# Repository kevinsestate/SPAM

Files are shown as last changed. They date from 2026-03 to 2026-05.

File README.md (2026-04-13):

# SPAM — Scanner for Polarized Anisotropic Materials

A local desktop application for scanning and extracting electromagnetic material tensors (ε, μ) from polarized RF measurements. Runs standalone on Raspberry Pi — no web server required.

## Features

- **Dual-polarization sweep**: Two full 0°–80° arm sweeps per run — horn at 0° (horizontal) then 90° (vertical) — servo-controlled automatically
- **Real-time S-parameter display**: Live S₂₁/S₁₁ magnitude and phase at each angle
- **T-matrix extraction**: Progressive inverse solver extracts diagonal ε/μ tensors from the full dual-pol S-matrix
- **Calibrated measurements**: Through + Reflect calibration sweep stores per-angle reference voltages
- **Live ADC oscilloscope**: Background I/Q stream at ~300 samp/s displayed in GUI
- **Data export**: JSON and CSV with all S-param fields + extraction results appended
- **Debug log**: All events written to `~/SPAM/spam_run.log` (survives crashes)
- **Remote access**: VNC-capable (x11vnc on X11 session) for headless operation

## Current Implementation Status (2026-04-13)

- **AD7193 SPI**: Operational — `ID=0xA2`, finite I/Q at 4800 Hz data rate, 4 MHz SPI
- **Motor control**: I2C polling of MCU status register (GPIO ISR not available on this kernel)
- **Servo**: HPS-2518MG on GPIO 18 — calibrated 850 µs = 0° (H), 1800 µs = 90° (V); jitter-free (PWM released after each move)
- **Dual-pol sweep**: Sweep 1 at horn 0°, servo rotates to 90°, Sweep 2 at horn 90°, returns home
- **RF switch**: Code complete — enable in Settings → Connection Setup once switch is physically wired
- **Calibration**: Through + Reflect sweep at pol-0 implemented; pol-90 cal deferred
- **Extraction**: Fires automatically after dual sweep if calibration data is loaded; builds 4×4 S-matrix from paired pol-0/pol-90 measurements

## Tech Stack

- **Python 3.9+**: Core application language
- **Tkinter**: GUI framework (included with Python)
- **Matplotlib**: Data visualization and graphing
- **SQLAlchemy**: ORM for database operations
- **SQLite**: Local database (no server required)

## Project Structure

```
SPAM/
├── GUI.py                  # Thin entry point (backward compat)
├── app.py                  # Application assembly (SPAMGui from mixins)
├── __main__.py             # Enables: python -m spam
├── pyproject.toml          # Python packaging config
├── requirements.txt        # Legacy dependency list
├── start_spam.sh           # Startup script for Linux/Raspberry Pi
├── start_spam.bat          # Startup script for Windows
├── spam_config.json        # GUI / ADC connection defaults (local)
├── spam_calc.py            # Backward-compat shim -> core/
├── spam_optimizer.py       # Backward-compat shim -> core/
├── core/
│   ├── spam_calc.py        # Transmission-matrix math (forward + S->T)
│   └── spam_optimizer.py   # Progressive inverse extraction
├── docs/                   # Handoff, benchmarks, integration notes, hardware PDFs (see docs/README.md)
├── gui/
│   ├── themes.py           # Theme palettes and fonts
│   ├── widgets.py          # Styled widget factory
│   ├── config.py           # Config persistence
│   ├── hardware_mixin.py   # Hardware init and motor control
│   ├── db_helpers.py       # Database CRUD helpers
│   ├── measurement.py      # Measurement sweep worker
│   ├── extraction.py       # Material extraction worker
│   ├── graphs.py           # Center panel graphs
│   ├── callbacks.py        # Status, calibrate, export, help
│   ├── debug_console.py    # Debug console window
│   ├── panels/             # Menu, status bar, sidebar, detail panel
│   └── dialogs/            # Extraction, parameters, connection dialogs
├── backend/
│   ├── database.py         # Database configuration
│   └── models.py           # SQLAlchemy models
├── hardware/
│   ├── ad7193.py           # AD7193 ADC driver (SPI)
│   ├── rf_switch.py        # RF switch controller (GPIO)
│   └── servo.py            # HPS-2518MG servo driver (pigpio/RPi.GPIO)
├── tests/
│   ├── test_spam_calc.py   # T-matrix validation tests
│   └── test_optimizer.py   # Extraction validation tests
├── scripts/pi/             # Raspberry Pi utilities (ADC, servo calibration)
├── Simulated Spam Calculations/
│   ├── *.mat               # Simulated validation datasets
│   └── *.m                 # MATLAB reference scripts
├── archive/
│   └── legacy/             # Non-active archived artifacts (includes old GUI snapshots)
└── README.md
```

Local runtime files (often gitignored): `spam.db`, `venv/`, `__pycache__/`, `spam_scanner.egg-info/`.

### Raspberry Pi ADC scripts (`scripts/pi/`)

Build and run on the Pi (Linux only; requires SPI enabled and `g++` for C++ tools):

| Script / binary | Purpose |
|---|---|
| `check_adc_lowlevel.py` | Short I/Q sanity check; optional `--benchmark-raw`, `--binary-out`, `--result-json` |
| `live_adc_view.py` | Live plot and/or benchmark; use `--data-rate`, `--spi-speed`, `--mode max-rate`, `--acq-mode stream`, `--benchmark-raw`, `--result-json` |
| `adc_fast_capture.py` | Optional native fast path hook + Python fallback |
| `servo_test.py` | **Interactive servo calibration** — `scan`, `sweep`, `min<us>`, `max<us>`, angle commands |
| `spi_ad7193_benchmark.cpp` | Raw SPI throughput vs clock (not full ADC protocol) |
| `ad7193_cpp_benchmark.cpp` | Full AD7193 driver in C++ + **pair/s** benchmark (compare to `live_adc_view.py`) |

Example (high output rate, benchmark only):

```bash
cd SPAM && source venv/bin/activate
python scripts/pi/live_adc_view.py --data-rate 4800 --spi-speed 2000000 \
  --mode max-rate --acq-mode stream --benchmark-raw --no-plot --duration 30 --result-json
```

Compile C++ tools:

```bash
cd SPAM/scripts/pi
g++ -O3 -std=c++17 spi_ad7193_benchmark.cpp -o spi_ad7193_benchmark
g++ -O3 -std=c++17 ad7193_cpp_benchmark.cpp -o ad7193_cpp_benchmark
```

(`-O3` uses the letter **O**, not zero.)

### Active vs Archive

- **Active runtime/test path**: `app.py`, `GUI.py`, `core/`, `gui/`, `backend/`, `hardware/`, `tests/`, startup scripts.
- **Archive path**: `archive/legacy/` contains non-active or superseded artifacts kept for reference (not used by launch scripts).

## Installation

### Prerequisites

- **Python 3.9 or higher**
- **Tkinter** (GUI framework - usually included with Python)
  - On Raspberry Pi/Linux: `sudo apt-get install python3-tk`
  - On Windows/Mac: Usually pre-installed with Python

### Windows Installation

#### Option 1: Quick Start (Recommended)

1. **Download or clone the repository:**
   ```powershell
   git clone https://github.com/kevinsestate/SPAM.git
   cd SPAM
   ```

2. **Run the startup script:**
   ```powershell
   .\start_spam.bat
   ```
   
   The script will automatically:
   - Check if Python is installed
   - Create a virtual environment (if needed)
   - Install the project and all dependencies
   - Launch the GUI application

#### Option 2: pip install (Standard Python)

1. **Clone and install:**
   ```powershell
   git clone https://github.com/kevinsestate/SPAM.git
   cd SPAM
   pip install -e .
   ```

2. **Launch (any of these work):**
   ```powershell
   spam                # CLI entry point
   python -m spam      # Module entry point
   python GUI.py       # Direct script
   ```

#### Option 3: Manual Installation

1. **Navigate to the project directory:**
   ```powershell
   cd SPAM
   ```

2. **Create a virtual environment:**
   ```powershell
   python -m venv venv
   .\venv\Scripts\activate
   ```
   
   If you get an execution policy error:
   ```powershell
   Set-ExecutionPolicy -ExecutionPolicy RemoteSigned -Scope CurrentUser
   ```

3. **Install:**
   ```powershell
   pip install -e .
   ```

4. **Run:**
   ```powershell
   spam
   ```

### Linux / Raspberry Pi Installation

#### Option 1: Quick Start (Recommended)

1. **Clone or download the repository:**
   ```bash
   git clone https://github.com/kevinsestate/SPAM.git
   cd SPAM
   chmod +x start_spam.sh
   ```

2. **Run the application:**
   ```bash
   ./start_spam.sh
   ```
   
   The script will automatically:
   - Check if Python 3 is installed
   - Create a virtual environment (if needed)
   - Install the project and all dependencies
   - Launch the GUI application

#### Option 2: pip install (Standard Python)

1. **Clone and install:**
   ```bash
   git clone https://github.com/kevinsestate/SPAM.git
   cd SPAM
   pip install -e .
   ```

   For Raspberry Pi with hardware support:
   ```bash
   pip install -e ".[rpi]"
   ```

2. **Launch:**
   ```bash
   spam                # CLI entry point
   python -m spam      # Module entry point
   python3 GUI.py      # Direct script
   ```

#### Option 3: Manual Installation

1. **Install Tkinter (if not already installed):**
   ```bash
   sudo apt-get update
   sudo apt-get install python3-tk
   ```

2. **Set up and install:**
   ```bash
   cd SPAM
   python3 -m venv venv
   source venv/bin/activate
   pip install -e .
   ```

3. **Run:**
   ```bash
   spam
   ```

## Usage Guide

### First Time Setup

1. **Configure Connection Settings** (if using hardware):
   - Go to **Settings → Connection Setup**
   - Configure signal input settings (ADC channels, sampling rate, etc.)
   - Configure serial port settings (if using serial connection)
   - Click **"Save"** to store settings

2. **Adjust Measurement Parameters** (optional):
   - Go to **Settings → Adjust Parameters**
   - Set frequency, power level, angle step, and measurement interval
   - Click **"Save"** to apply changes

### Calibration Process

Before taking measurements, calibrate the system to convert raw ADC voltages to S-parameters:

1. Click **"Calibrate"** in the sidebar
2. **Step 1 — Through (empty fixture):**
   - Remove ALL material from the fixture
   - Click **OK** — arm sweeps 0°→80°, records per-angle transmitted voltage
3. **Step 2 — Reflect (metal sheet):**
   - Place a metal sheet in the fixture
   - Click **OK** — arm sweeps again, records reflected voltage
4. Calibration stored in DB — loaded automatically on next launch

> **Note:** Set `cal_d_m` and `cal_d_sheet_m` in **Settings → Connection Setup** to your physical rig geometry (metres) for accurate phase correction. Default is 0.0 (phase correction disabled).

### Taking Measurements

1. **Start a Measurement Session:**
   - Click **"Start Measurement"** in the sidebar
   - **Sweep 1**: arm sweeps 0°→80° at 5° steps with horn at 0° (horizontal)
   - Servo automatically rotates horn to 90°
   - **Sweep 2**: arm sweeps 0°→80° with horn at 90° (vertical)
   - Servo returns horn to 0° and extraction fires automatically
   - All data saved to DB in real-time

2. **Monitor Progress:**
   - Right panel shows: Angle, Polarization, Sweep progress (e.g. `Sweep 1/2 — 8/17 pts`), Cal Data status, live S₂₁/S₁₁
   - Center graphs: S-parameter plots with pol-0 (blue) and pol-90 (orange) colour coding, live ADC oscilloscope

3. **Stop Measurement:**
   - Click **"Stop Measurement"** — motors return home, servo resets to 0°

### Viewing Results

- **Real-Time Graphs:**
  - Center panel shows permittivity and permeability vs angle
  - Graphs update automatically every second
  - Scroll to view control parameters and non-idealities sections

- **Measurement Data Panel:**
  - Right panel displays latest measurement values
  - S-Parameters show magnitude and phase
  - System status indicates current state

- **View Results Summary:**
  - Click **"View Results"** to see statistics
  - Shows total measurements, angle range, min/max/average values

### Managing Data

1. **Clear Measurements:**
   - Click **"Clear Measurements"** to delete all data
   - Confirmation dialog will appear
   - **Warning:** This action cannot be undone

2. **Export Data:**
   - Click **"Export Data"** or use **File → Export Data**
   - Choose format:
     - **JSON**: measurements array + extraction result block (ε tensor, μ tensor, fit error)
     - **CSV**: one row per measurement point with all S-param fields; extraction result appended as footer
   - Data exported in chronological order (angle 0 = row 1)

### Understanding the Interface

**Left Sidebar:**
- Action buttons for calibration, measurement control, and data management
- Version information at the bottom

**Center Panel:**
- Real-time measurement graphs (Permittivity and Permeability)
- Control Parameters section (frequency, power, angle step, interval)
- Non-Idealities & Compensation section (calibration error, noise, temperature, humidity)

**Right Panel:**
- Measurement section: Angle, Polarization, Sweep progress, Cal Data status, Status
- Extracted Material: εr diagonal, μr diagonal, Fit Error
- Motor: status and position
- S-Parameters: live S₁₁, S₁₂, S₂₁, S₂₂
- Extraction Config: status, thickness, tensor type
- Parameters: frequency, power, angle step, interval

**Status Bar (Bottom):**
- Current system status
- Last update timestamp

### Database

- All measurements are stored in a local SQLite database (`spam.db`)
- The database is created automatically on first run
- No database server is required - everything runs locally
- Database file is stored in the project directory

## Hardware Integration

### System Architecture

**RF Chain (24 GHz):**
- **Gunn Diode Oscillator** → Amplifier → Splitter
  - TX path → TX Horn Antenna (radiates into free space through sample)
  - LO path → Mixer
- **RX Horn Antennas**: Transmitted (RXT) and Reflected (RXp)
- **SP2T RF Switch** (GPIO 22): selects TX or RX antenna path → Mixer input
- **Mixer**: downconverts to IF — produces IF-I and IF-Q
- **AD7193 (Pmod AD5)**: 24-bit SPI ADC reads IF-I and IF-Q at 4800 Hz

**Control System (Raspberry Pi):**
- **AD7193** via SPI (`/dev/spidev0.0`, 4 MHz)
- **Motor controller MCU** via I2C (address `0x55`) — 2-axis arm + material rotation
- **HPS-2518MG Servo** via GPIO 18 PWM (pigpio) — rotates horn antenna for polarization
- **SP2T RF Switch** via GPIO 22 (optional, enable in settings)

### Connection Setup

All hardware parameters are in **Settings → Connection Setup**:

| Setting | Default | Notes |
|---|---|---|
| SPI Bus / CS | 0 / 0 | AD7193 on SPI0.0 |
| SPI Speed | 4000000 | 4 MHz |
| ADC Gain | 1 | Increase for weak signals |
| Data Rate (Hz) | 4800 | Higher = faster, more noise |
| Samples/Point | 8 | Averaged per angle |
| Enable RF Switch | 0 | Set to 1 once switch is wired |
| Switch GPIO Pin | 22 | BCM numbering |
| Servo GPIO Pin | 18 | BCM numbering |
| MCU Address | 0x55 | I2C motor controller |
| ISR Pin | 17 | Motor position interrupt |
| Coupler Sep. d (m) | 0.0 | **Measure and set for calibration** |
| Ref Plane d_sheet (m) | 0.0 | **Measure and set for calibration** |

### Servo Calibration

To recalibrate the horn servo (e.g. after mechanical adjustment):

```bash
cd ~/SPAM
python3 scripts/pi/servo_test.py
```

Use `scan` to find physical stops, `min<us>` / `max<us>` to set endpoints, `sweep` to verify, `q` to print final values. Update `_PULSE_MIN_US` / `_PULSE_MAX_US` in `hardware/servo.py`.

### Remote Access (VNC)

Enable x11vnc on the Pi (X11 session required — run `sudo raspi-config nonint do_wayland W1` first if on Wayland):

```bash
x11vnc -display :0 -nopw -forever -bg -noxdamage
# Connects on port 5901
```

Connect from Windows using RealVNC Viewer: `<pi-ip>:5901`

## Troubleshooting

### Tkinter not found (Linux/Raspberry Pi)
```bash
sudo apt-get update
sudo apt-get install python3-tk
```

### Permission denied on startup script
```bash
chmod +x start_spam.sh
```

### Database errors
- The database file (`spam.db`) is created automatically
- If you encounter errors, try deleting `spam.db` and restarting the application

### Display issues on Raspberry Pi
- If the GUI doesn't appear, make sure you're running in a graphical environment
- For headless setups, you may need to set up X11 forwarding or use a VNC server

## Development

### Adding New Features

The application uses a mixin-based architecture:
- `app.py`: Assembles `SPAMGui` from mixin classes
- `gui/`: Mixin modules (widgets, config, hardware, measurement, extraction, graphs, etc.)
- `core/`: Scientific computation (T-matrix math, inverse solver)
- `backend/`: Database models and configuration
- `hardware/`: ADC and RF switch drivers
- `tests/`: Validation test suites

### Testing

**Automated math checks** (from repo root):

```bash
python tests/test_spam_calc.py
python tests/test_optimizer.py
```

**Manual / GUI:** calibration, measurement start/stop, export (JSON/CSV), live graphs.

## Notes

- This is a **local-only** application - no web server or network access required
- All data is stored locally in SQLite
- The application is designed to run standalone on a Raspberry Pi
- The web frontend (React) and FastAPI backend are no longer needed for local operation

## Integration testing and reports

- **Transmission-matrix / extraction (simulation):** [docs/integration/TRANSMISSION_MATRIX_INTEGRATION_TEST_RESULTS.md](docs/integration/TRANSMISSION_MATRIX_INTEGRATION_TEST_RESULTS.md)
- **ADC / RF switch software bring-up (hardware scope):** [docs/integration/INTEGRATION_TEST_RESULTS.md](docs/integration/INTEGRATION_TEST_RESULTS.md)
- **Benchmark summary + LaTeX report:** [docs/benchmarks/benchmark_results.md](docs/benchmarks/benchmark_results.md), [docs/benchmarks/benchmark_report.tex](docs/benchmarks/benchmark_report.tex)
- **Index of all docs:** [docs/README.md](docs/README.md)

## License

This project is provided as-is for educational and development purposes.

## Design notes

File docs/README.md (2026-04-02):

# Documentation index

| Path | Contents |
|---|---|
| [HANDOFF_STATUS.md](HANDOFF_STATUS.md) | Quick Pi / ADC / extraction handoff for operators and agents |
| [reference/hardware/](reference/hardware/) | AD7193 / Pmod AD5 PDFs and Raspberry Pi pinout image |
| [benchmarks/](benchmarks/) | `benchmark_results.md`, `benchmark_report.tex` (Overleaf), `artifacts/` (captured run logs) |
| [integration/](integration/) | Transmission-matrix and hardware integration test write-ups |

Run math validation from repo root:

```bash
python tests/test_spam_calc.py
python tests/test_optimizer.py
```

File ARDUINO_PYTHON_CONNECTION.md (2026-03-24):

# Arduino and Python Connection Guide

## Overview

There are several ways to connect Arduino with Python for the SPAM project. This guide explains the different methods, their pros/cons, and how they relate to your current setup.

## Connection Methods

### 1. Serial Communication (USB/UART)

**How it works:**
- Arduino connects to computer via USB cable
- Python uses `pyserial` library to communicate over serial port
- Data sent as text strings or binary data
- Works on Windows, Linux, and Mac

**Pros:**
- ✅ Simple and straightforward
- ✅ Works on all platforms
- ✅ No additional hardware needed (just USB cable)
- ✅ Easy to debug (can use Serial Monitor)
- ✅ Fast communication (up to 115200+ baud)

**Cons:**
- ❌ Requires USB cable connection
- ❌ One Arduino per USB port
- ❌ Not ideal for multiple devices

**Python Code Example:**
```python
import serial
import time

# Open serial connection
arduino = serial.Serial('COM3', 115200, timeout=1)  # Windows: COM3, Linux: /dev/ttyUSB0 or /dev/ttyACM0
time.sleep(2)  # Wait for Arduino to initialize

# Send command to move motor
arduino.write(b'M,1,45.0\n')  # Move motor 1 to 45 degrees

# Read response
response = arduino.readline().decode('utf-8').strip()
print(f"Arduino response: {response}")

# Close connection
arduino.close()
```

**Arduino Code Example:**
```cpp
void setup() {
  Serial.begin(115200);
}

void loop() {
  if (Serial.available() > 0) {
    String command = Serial.readStringUntil('\n');
    // Process command (e.g., "M,1,45.0" = Move motor 1 to 45°)
    processCommand(command);
  }
}
```

---

### 2. I2C Communication (Current Method)

**How it works:**
- Arduino acts as I2C slave device
- Raspberry Pi (or other I2C master) communicates via I2C bus
- Multiple devices can share same I2C bus (different addresses)
- Uses SDA (data) and SCL (clock) wires

**Pros:**
- ✅ Multiple devices on same bus (up to 128 addresses)
- ✅ Only 2 wires needed (plus power/ground)
- ✅ Standard protocol, well-supported
- ✅ Already implemented in your GUI code
- ✅ Good for Raspberry Pi integration

**Cons:**
- ❌ Requires I2C-capable hardware (Raspberry Pi, not standard PC)
- ❌ Limited distance (short wires)
- ❌ More complex than serial
- ❌ Address conflicts if not careful

**Your Current Implementation:**
Your GUI already uses I2C! In `GUI.py`, the `_initialize_motor_control()` function:
- Opens I2C bus using `SMBus`
- Communicates with microcontroller at address `0x55`
- Sends 6-byte commands: `[command, motor_num, float_bytes...]`

**Python Code (Already in your code):**
```python
from smbus import SMBus
import struct

bus = SMBus(1)  # I2C bus 1 on Raspberry Pi
address = 0x55  # Arduino I2C address

# Send motor position command
position = 45.0  # degrees
packed = struct.pack('<f', position)  # Pack as 4-byte float
message = [1, 1] + list(packed)  # [command, motor_num, float_bytes]
bus.write_i2c_block_data(address, 0x00, message)
```

**Arduino I2C Code:**
```cpp
#include <Wire.h>

#define I2C_ADDRESS 0x55

void setup() {
  Wire.begin(I2C_ADDRESS);
  Wire.onReceive(receiveEvent);
  Wire.onRequest(requestEvent);
}

void receiveEvent(int bytes) {
  byte data[6];
  int i = 0;
  while (Wire.available() && i < 6) {
    data[i++] = Wire.read();
  }
  // Process command: data[0]=command, data[1]=motor, data[2-5]=position
  processMotorCommand(data);
}

void requestEvent() {
  // Send status back to master
  Wire.write(statusByte);
}
```

---

### 3. Firmata Protocol

**How it works:**
- Arduino runs Firmata firmware (standard library)
- Python uses `pyfirmata` library
- High-level abstraction - control pins directly from Python
- No need to write Arduino code

**Pros:**
- ✅ Very easy to use
- ✅ No Arduino programming needed
- ✅ Direct pin control from Python
- ✅ Good for prototyping

**Cons:**
- ❌ Less efficient than custom code
- ❌ Limited to Firmata capabilities
- ❌ Not ideal for complex motor control
- ❌ Requires Firmata library on Arduino

**Python Code:**
```python
from pyfirmata import Arduino, util
import time

board = Arduino('COM3')  # or '/dev/ttyUSB0' on Linux

# Control digital pin
board.digital[9].write(1)  # Set pin 9 HIGH

# Read analog pin
value = board.analog[0].read()  # Read analog pin A0

board.exit()
```

---

## Comparison for Your SPAM Project

### Current Setup (I2C)
- **Status**: ✅ Already implemented
- **Hardware**: Raspberry Pi with I2C bus
- **Arduino**: Configured as I2C slave at address 0x55
- **Communication**: 6-byte commands for motor control
- **Best for**: Production system on Raspberry Pi

### Alternative: Serial Communication
- **Status**: ⚠️ Would need to modify GUI code
- **Hardware**: Any computer with USB port
- **Arduino**: Standard USB connection
- **Communication**: Text-based commands (e.g., "M,1,45.0")
- **Best for**: Development, Windows testing, simpler setup

---

## Integration with Your GUI

### Option 1: Keep I2C (Recommended for Raspberry Pi)
Your current setup is already working! The GUI:
1. Initializes I2C bus in `_initialize_motor_control()`
2. Sends commands via `_send_motor_command()`
3. Reads status via GPIO interrupts
4. Works seamlessly on Raspberry Pi

**No changes needed** if you're using Raspberry Pi!

### Option 2: Add Serial Support (For Windows/Development)
To add serial support alongside I2C:

1. **Add serial import:**
```python
import serial
```

2. **Modify `_initialize_motor_control()` to detect connection type:**
```python
def _initialize_motor_control(self):
    # Try I2C first (Raspberry Pi)
    if platform.system() == 'Linux':
        try:
            from smbus import SMBus
            # ... existing I2C code ...
        except:
            pass
    
    # Fall back to Serial (Windows or if I2C fails)
    try:
        port = self.connection_settings.get('serial_port', 'COM3')
        baud = int(self.connection_settings.get('serial_baud', '115200'))
        self.arduino_serial = serial.Serial(port, baud, timeout=1)
        self.motor_control_enabled = True
        self.motor_control_type = 'serial'
    except:
        self.motor_control_enabled = False
```

3. **Modify `_send_motor_command()` to support both:**
```python
def _send_motor_command(self, motor_num, position, command=1):
    if self.motor_control_type == 'i2c':
        # Existing I2C code
        ...
    elif self.motor_control_type == 'serial':
        # Serial command
        cmd = f"M,{motor_num},{position:.2f}\n"
        self.arduino_serial.write(cmd.encode())
        response = self.arduino_serial.readline().decode().strip()
        return response.startswith("OK")
```

---

## Recommended Approach

### For Raspberry Pi (Production):
**Use I2C** - Already implemented, efficient, supports multiple devices

### For Windows Development/Testing:
**Add Serial support** - Easier to test without Raspberry Pi hardware

### For Both:
**Hybrid approach** - Detect platform and use appropriate method:
- Linux → I2C
- Windows → Serial
- Fallback to simulation if neither works

---

## Arduino Code Requirements

### For I2C (Current):
- Arduino must be configured as I2C slave
- Address: 0x55 (or configurable)
- Must handle 6-byte commands: `[command, motor, float_bytes...]`
- Must send status via GPIO interrupt pin

### For Serial (Alternative):
- Arduino must read serial commands
- Parse text commands like "M,1,45.0"
- Send responses like "OK:POSITION:45.0"
- Handle status updates

---

## Troubleshooting

### I2C Issues:
- **"No device at address"**: Check I2C address, run `i2cdetect -y 1` on Pi
- **"Permission denied"**: Add user to `i2c` group: `sudo usermod -aG i2c $USER`
- **"Input/output error"**: Check wiring (SDA/SCL), verify power

### Serial Issues:
- **"Port not found"**: Check COM port (Windows Device Manager) or `/dev/tty*` (Linux)
- **"Permission denied"**: Add user to `dialout` group: `sudo usermod -aG dialout $USER`
- **"Timeout"**: Check baud rate matches Arduino code

---

## Summary

**Your current I2C setup is perfect for Raspberry Pi!** It's already integrated and working. If you need to test on Windows or want a simpler development setup, you can add serial communication as an alternative. The choice depends on:

- **Platform**: Raspberry Pi → I2C, Windows → Serial
- **Complexity**: I2C is more complex but more capable
- **Multiple devices**: I2C supports multiple devices on one bus
- **Distance**: Serial works over longer USB cables

Both methods work well - I2C is better for production, Serial is easier for development!

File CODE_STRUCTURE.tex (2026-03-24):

\documentclass[11pt,a4paper]{article}
\usepackage[utf8]{inputenc}
\usepackage[T1]{fontenc}
\usepackage{geometry}
\usepackage{graphicx}
\usepackage{hyperref}
\usepackage{listings}
\usepackage{xcolor}
\usepackage{amsmath}
\usepackage{tikz}
\usepackage{float}
\usepackage{enumitem}

% Page setup
\geometry{margin=1in}
\hypersetup{
    colorlinks=true,
    linkcolor=blue,
    filecolor=magenta,      
    urlcolor=cyan,
    pdftitle={SPAM Code Structure},
    pdfauthor={SPAM Development Team}
}

% Code listing style
\lstset{
    language=Python,
    basicstyle=\ttfamily\small,
    keywordstyle=\color{blue}\bfseries,
    commentstyle=\color{green!60!black},
    stringstyle=\color{red},
    numbers=left,
    numberstyle=\tiny\color{gray},
    stepnumber=1,
    numbersep=5pt,
    backgroundcolor=\color{gray!10},
    frame=single,
    breaklines=true,
    breakatwhitespace=true,
    tabsize=4,
    showspaces=false,
    showstringspaces=false
}

\title{\textbf{SPAM Code Structure Documentation}\\
\large Scanner for Polarized Anisotropic Materials\\
\large Code Architecture Overview}
\author{SPAM Development Team}
\date{\today}

\begin{document}

\maketitle
\tableofcontents
\newpage

\section{Project Overview}

The SPAM (Scanner for Polarized Anisotropic Materials) project is a Python-based desktop application for automated material characterization. The codebase is organized into a modular structure with clear separation between GUI, database, and hardware control components.

\section{Project Structure}

\subsection{Directory Layout}
\begin{verbatim}
SPAM/
├── GUI.py                    # Main application file
├── motor_control_status.py   # Motor control reference
├── requirements.txt          # Python dependencies
├── start_spam.sh            # Linux startup script
├── start_spam.bat           # Windows startup script
├── spam_config.json         # Configuration file (auto-generated)
├── spam.db                  # SQLite database (auto-generated)
├── backend/
│   ├── __init__.py          # Package marker
│   ├── database.py          # Database configuration
│   └── models.py            # Database models
└── venv/                    # Virtual environment
\end{verbatim}

\subsection{Key Files}

\begin{description}
    \item[\texttt{GUI.py}] Main application file containing the entire GUI and application logic (3000+ lines)
    \item[\texttt{backend/database.py}] Database connection and session management
    \item[\texttt{backend/models.py}] SQLAlchemy ORM models for data storage
    \item[\texttt{motor\_control\_status.py}] Reference implementation for motor control
    \item[\texttt{requirements.txt}] Python package dependencies
    \item[\texttt{start\_spam.sh/bat}] Platform-specific startup scripts
\end{description}

\section{Main Components}

\subsection{GUI.py - Main Application}

\texttt{GUI.py} is the core of the application, containing a single main class that handles all functionality.

\subsubsection{SPAMGui Class}
The \texttt{SPAMGui} class inherits from \texttt{tk.Tk}, making it the main application window.

\textbf{Key Responsibilities:}
\begin{itemize}
    \item GUI component creation and layout
    \item User interaction handling
    \item Measurement workflow management
    \item Motor control integration
    \item Database operations
    \item Real-time data visualization
\end{itemize}

\textbf{Initialization Flow:}
\begin{enumerate}
    \item Window setup (size, title, colors)
    \item State variable initialization
    \item Load configuration from JSON file
    \item Create all UI components
    \item Initialize database connection
    \item Initialize motor control (if on Raspberry Pi)
    \item Start periodic display updates
\end{enumerate}

\subsubsection{Main Methods by Category}

\textbf{UI Creation Methods:}
\begin{itemize}
    \item \texttt{\_create\_menu()} - Creates menu bar
    \item \texttt{\_create\_sidebar()} - Creates left control panel
    \item \texttt{\_create\_info\_panel()} - Creates right info display
    \item \texttt{\_create\_center\_panel()} - Creates graph area
    \item \texttt{\_create\_control\_panel()} - Creates bottom control panel
    \item \texttt{\_create\_status\_bar()} - Creates status bar
\end{itemize}

\textbf{Measurement Methods:}
\begin{itemize}
    \item \texttt{\_on\_start\_measurement()} - Starts measurement thread
    \item \texttt{\_on\_stop\_measurement()} - Stops measurement
    \item \texttt{\_measurement\_worker()} - Background measurement thread
    \item \texttt{\_on\_calibrate()} - Two-step calibration process
\end{itemize}

\textbf{Motor Control Methods:}
\begin{itemize}
    \item \texttt{\_initialize\_motor\_control()} - Initializes I2C/GPIO
    \item \texttt{\_send\_motor\_command()} - Sends I2C motor commands
    \item \texttt{\_wait\_for\_motor\_position()} - Waits for position reached
\end{itemize}

\textbf{Database Methods:}
\begin{itemize}
    \item \texttt{\_create\_measurement()} - Stores measurement in database
    \item \texttt{\_create\_calibration()} - Stores calibration record
    \item \texttt{\_get\_measurements()} - Retrieves measurements
\end{itemize}

\textbf{Display Methods:}
\begin{itemize}
    \item \texttt{\_update\_graphs()} - Updates all graphs
    \item \texttt{\_update\_display()} - Periodic display refresh
    \item \texttt{\_update\_status()} - Updates status bar
\end{itemize}

\textbf{Settings Methods:}
\begin{itemize}
    \item \texttt{\_on\_connection\_setup()} - Connection settings dialog
    \item \texttt{\_on\_adjust\_parameters()} - Parameter adjustment dialog
    \item \texttt{\_load\_connection\_settings()} - Loads config from JSON
    \item \texttt{\_save\_connection\_settings()} - Saves config to JSON
\end{itemize}

\subsubsection{Debug Console Class}
The \texttt{DebugConsole} class is a separate window for diagnostics:
\begin{itemize}
    \item System information tab
    \item Database information tab
    \item Measurement log tab
    \item Console log tab
    \item Configuration tab
    \item Motor control tab
\end{itemize}

\subsection{Backend Package}

\subsubsection{database.py}
Handles database connection and session management.

\textbf{Key Components:}
\begin{itemize}
    \item \texttt{SQLALCHEMY\_DATABASE\_URL} - SQLite database path
    \item \texttt{engine} - SQLAlchemy engine instance
    \item \texttt{SessionLocal} - Session factory for database operations
    \item \texttt{Base} - Base class for ORM models
\end{itemize}

\textbf{Purpose:}
\begin{itemize}
    \item Creates SQLite database file (\texttt{spam.db})
    \item Manages database connections
    \item Provides session factory for database operations
\end{itemize}

\subsubsection{models.py}
Defines database schema using SQLAlchemy ORM.

\textbf{Measurement Model:}
\begin{itemize}
    \item Stores angle sweep measurement data
    \item Fields: id, angle, permittivity, permeability, transmitted/reflected power/phase, timestamp
    \item Indexed on angle and timestamp for fast queries
\end{itemize}

\textbf{Calibration Model:}
\begin{itemize}
    \item Stores calibration records
    \item Fields: id, timestamp, parameters (JSON), status
    \item Used for two-step calibration process
\end{itemize}

\section{Data Flow}

\subsection{Application Startup}
\begin{enumerate}
    \item \texttt{main()} function called
    \item Creates \texttt{SPAMGui} instance
    \item \texttt{\_\_init\_\_()} initializes all components
    \item Database tables created (if first run)
    \item Configuration loaded from \texttt{spam\_config.json}
    \item Motor control initialized (if on Linux)
    \item GUI displayed and ready for user interaction
\end{enumerate}

\subsection{Measurement Workflow}
\begin{enumerate}
    \item User clicks "Start Measurement"
    \item \texttt{\_on\_start\_measurement()} called
    \item Measurement thread spawned (\texttt{\_measurement\_worker})
    \item Thread loops through angles (0° to 90°):
    \begin{enumerate}
        \item Send motor command via I2C
        \item Wait for position reached
        \item Read ADC signals (I/Q channels)
        \item Calculate power and phase
        \item Calculate material properties (ε, μ)
        \item Store measurement in database
        \item Update GUI graphs and displays
        \item Increment angle
    \end{enumerate}
    \item Thread completes, updates status
\end{enumerate}

\subsection{Data Storage Flow}
\begin{enumerate}
    \item Measurement data calculated
    \item \texttt{\_create\_measurement()} called
    \item Creates \texttt{Measurement} object with all fields
    \item Adds to database session
    \item Commits transaction
    \item Data persisted to \texttt{spam.db}
\end{enumerate}

\subsection{Display Update Flow}
\begin{enumerate}
    \item \texttt{\_update\_display()} called periodically (every 1 second)
    \item Calls \texttt{\_update\_graphs()}
    \item Queries database for latest measurements
    \item Extracts data arrays (angles, permittivity, permeability, power, phase)
    \item Updates Matplotlib graphs
    \item Updates info panel values
    \item Updates status indicators
    \item Schedules next update
\end{enumerate}

\section{Key Technologies}

\subsection{Python Libraries}
\begin{description}
    \item[\texttt{tkinter}] GUI framework (built-in)
    \item[\texttt{matplotlib}] Graph plotting and visualization
    \item[\texttt{sqlalchemy}] ORM for database operations
    \item[\texttt{numpy}] Numerical computations
    \item[\texttt{smbus}] I2C communication (Raspberry Pi)
    \item[\texttt{RPi.GPIO}] GPIO control (Raspberry Pi)
\end{description}

\subsection{Communication Protocols}
\begin{description}
    \item[\texttt{I2C}] Motor control communication (Raspberry Pi)
    \item[\texttt{GPIO}] Interrupt handling for motor status
    \item[\texttt{SQLite}] Local database storage
    \item[\texttt{JSON}] Configuration file format
\end{description}

\section{Configuration Management}

\subsection{Configuration File}
Settings stored in \texttt{spam\_config.json}:
\begin{itemize}
    \item I2C bus number
    \item ADC I2C address
    \item IF-I and IF-Q channel numbers
    \item Sampling rate
    \item Microcontroller I2C address
    \item ISR GPIO pin number
\end{itemize}

\subsection{Configuration Flow}
\begin{enumerate}
    \item On startup: Load settings from JSON file
    \item If file doesn't exist: Use default values
    \item User changes settings via dialog
    \item Settings validated
    \item Saved to JSON file
    \item Motor control reinitialized with new settings
\end{enumerate}

\section{Motor Control Integration}

\subsection{I2C Communication}
\begin{itemize}
    \item Uses \texttt{smbus} library on Raspberry Pi
    \item Communicates with microcontroller at address 0x55
    \item Sends 6-byte commands: \texttt{[command, motor\_num, float\_bytes...]}
    \item Position encoded as 4-byte little-endian float
\end{itemize}

\subsection{GPIO Interrupts}
\begin{itemize}
    \item ISR pin (default: GPIO 17) configured for interrupts
    \item Interrupt handler reads status register
    \item Detects collision (bit 0x01) and position reached (bit 0x02)
    \item Updates GUI via thread-safe \texttt{self.after()} calls
\end{itemize}

\subsection{Platform Detection}
\begin{itemize}
    \item Windows: Motor control in simulation mode
    \item Linux: Full hardware integration
    \item Automatic detection via \texttt{platform.system()}
\end{itemize}

\section{Threading Model}

\subsection{Main Thread}
\begin{itemize}
    \item GUI event loop (Tkinter)
    \item Handles user interactions
    \item Updates display
    \item Manages UI components
\end{itemize}

\subsection{Measurement Thread}
\begin{itemize}
    \item Background worker for measurements
    \item Runs \texttt{\_measurement\_worker()} function
    \item Performs motor control and data acquisition
    \item Updates GUI via \texttt{self.after()} for thread safety
\end{itemize}

\subsection{Thread Safety}
\begin{itemize}
    \item GUI updates from background thread use \texttt{self.after()}
    \item Database operations are thread-safe (SQLAlchemy)
    \item Motor control uses proper synchronization
\end{itemize}

\section{Graph Visualization}

\subsection{Graph Types}
The application displays four real-time graphs:
\begin{enumerate}
    \item \textbf{Permittivity vs Angle} - Material permittivity over sweep
    \item \textbf{Permeability vs Angle} - Material permeability over sweep
    \item \textbf{Power vs Angle} - Transmitted and reflected power
    \item \textbf{Phase vs Angle} - Transmitted and reflected phase
\end{enumerate}

\subsection{Graph Implementation}
\begin{itemize}
    \item Uses Matplotlib's \texttt{FigureCanvasTkAgg} for embedding
    \item Graphs contained in scrollable frame
    \item Auto-scaling based on data range
    \item Real-time updates from database queries
    \item Professional styling with color scheme
\end{itemize}

\section{Database Schema}

\subsection{Measurements Table}
\begin{verbatim}
CREATE TABLE measurements (
    id INTEGER PRIMARY KEY,
    angle FLOAT NOT NULL,
    permittivity FLOAT NOT NULL,
    permeability FLOAT NOT NULL,
    transmitted_power FLOAT,
    reflected_power FLOAT,
    transmitted_phase FLOAT,
    reflected_phase FLOAT,
    timestamp DATETIME NOT NULL
);
\end{verbatim}

\subsection{Calibrations Table}
\begin{verbatim}
CREATE TABLE calibrations (
    id INTEGER PRIMARY KEY,
    timestamp DATETIME NOT NULL,
    parameters JSON,
    status VARCHAR NOT NULL
);
\end{verbatim}

\section{Error Handling}

\subsection{Error Types}
\begin{itemize}
    \item Hardware errors (I2C, GPIO failures)
    \item Database errors (connection, query failures)
    \item Measurement errors (motor timeouts, collisions)
    \item User input errors (invalid values)
\end{itemize}

\subsection{Error Handling Strategy}
\begin{itemize}
    \item Try-except blocks around critical operations
    \item User-friendly error messages
    \item Logging to debug console
    \item Graceful degradation (continue when possible)
    \item Status bar updates for user feedback
\end{itemize}

\section{Export Functionality}

\subsection{Export Formats}
\begin{itemize}
    \item \textbf{CSV}: Comma-separated values for spreadsheet import
    \item \textbf{JSON}: Structured data format for programmatic access
\end{itemize}

\subsection{Export Process}
\begin{enumerate}
    \item User clicks "Export" button
    \item Selects format (CSV or JSON)
    \item Chooses save location
    \item All measurements retrieved from database
    \item Data formatted and written to file
    \item File saved with timestamp in filename
\end{enumerate}

\section{Startup Scripts}

\subsection{start\_spam.sh (Linux)}
\begin{itemize}
    \item Checks Python installation
    \item Creates virtual environment if needed
    \item Installs dependencies
    \item Handles DNS/network issues
    \item Sets display for VNC
    \item Launches GUI application
\end{itemize}

\subsection{start\_spam.bat (Windows)}
\begin{itemize}
    \item Checks Python installation
    \item Creates virtual environment if needed
    \item Installs dependencies
    \item Launches GUI application
\end{itemize}

\section{Code Organization Principles}

\subsection{Modularity}
\begin{itemize}
    \item Single main class (\texttt{SPAMGui}) for GUI
    \item Separate backend package for database
    \item Clear method naming conventions
    \item Logical grouping of related methods
\end{itemize}

\subsection{Separation of Concerns}
\begin{itemize}
    \item GUI logic in \texttt{GUI.py}
    \item Database logic in \texttt{backend/}
    \item Configuration separate from code
    \item Hardware abstraction for platform differences
\end{itemize}

\subsection{Maintainability}
\begin{itemize}
    \item Clear method names (\texttt{\_create\_}, \texttt{\_on\_}, \texttt{\_update\_})
    \item Comprehensive comments
    \item Consistent code style
    \item Error handling throughout
\end{itemize}

\section{Key Design Patterns}

\subsection{Singleton Pattern}
\begin{itemize}
    \item Single \texttt{SPAMGui} instance
    \item Single database session
    \item Single configuration file
\end{itemize}

\subsection{Observer Pattern}
\begin{itemize}
    \item GUI updates observe database changes
    \item Status updates observe measurement state
    \item Graph updates observe new measurements
\end{itemize}

\subsection{Factory Pattern}
\begin{itemize}
    \item \texttt{SessionLocal} creates database sessions
    \item Measurement objects created via factory method
\end{itemize}

\section{Summary}

The SPAM codebase follows a clear, modular structure:
\begin{itemize}
    \item \textbf{Main File}: \texttt{GUI.py} contains all GUI and application logic
    \item \textbf{Backend}: Database models and configuration in \texttt{backend/}
    \item \textbf{Configuration}: Settings stored in JSON file
    \item \textbf{Database}: SQLite for local data storage
    \item \textbf{Hardware}: I2C/GPIO integration for Raspberry Pi
    \item \textbf{Threading}: Background measurement thread with thread-safe GUI updates
    \item \textbf{Visualization}: Real-time graphs using Matplotlib
\end{itemize}

The code is designed for maintainability, with clear separation between GUI, database, and hardware control components. The modular structure makes it easy to understand, modify, and extend functionality.

\end{document}

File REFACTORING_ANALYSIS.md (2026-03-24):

# GUI.py Refactoring Analysis

## Current State

- **File Size**: ~3,092 lines
- **Methods**: ~53 methods in SPAMGui class
- **Complexity**: Single monolithic file with all functionality

## Should You Split It Up?

### ✅ **YES - Benefits of Splitting:**

1. **Better Organization**
   - Easier to find specific functionality
   - Clear separation of concerns
   - Logical grouping of related methods

2. **Easier Maintenance**
   - Smaller files are easier to understand
   - Changes are isolated to specific modules
   - Less scrolling to find code

3. **Better Collaboration**
   - Multiple developers can work on different files
   - Fewer merge conflicts
   - Clearer ownership of code areas

4. **Improved Testing**
   - Can test individual modules separately
   - Easier to mock dependencies
   - Better unit test coverage

5. **Code Reusability**
   - Components can be reused in other projects
   - Clearer interfaces between modules

### ❌ **NO - Reasons to Keep It Together:**

1. **Current State Works**
   - Code is functional and working
   - No immediate problems

2. **Single Developer Project**
   - If you're the only developer, splitting may be overkill
   - Easier to see everything in one place

3. **Refactoring Risk**
   - Risk of introducing bugs during split
   - Time investment may not be worth it
   - Need to test everything again

4. **Tkinter Architecture**
   - Tkinter apps often have large main files
   - GUI components are tightly coupled
   - State management easier in single class

## Recommended Refactoring Structure

If you decide to refactor, here's a suggested structure:

```
SPAM/
├── GUI.py                    # Main application (orchestrator)
├── gui/
│   ├── __init__.py
│   ├── components/
│   │   ├── __init__.py
│   │   ├── menu.py           # Menu bar creation
│   │   ├── sidebar.py        # Sidebar panel
│   │   ├── info_panel.py     # Info panel
│   │   ├── center_panel.py   # Graph area
│   │   ├── control_panel.py  # Control panel
│   │   └── status_bar.py      # Status bar
│   ├── dialogs/
│   │   ├── __init__.py
│   │   ├── connection_setup.py
│   │   ├── parameter_adjust.py
│   │   └── debug_console.py
│   └── graphs/
│       ├── __init__.py
│       └── graph_manager.py   # Graph creation and updates
├── hardware/
│   ├── __init__.py
│   └── motor_control.py       # Motor control logic
├── measurement/
│   ├── __init__.py
│   ├── measurement_worker.py  # Background measurement thread
│   └── calibration.py         # Calibration logic
├── data/
│   ├── __init__.py
│   ├── database.py            # Database operations (move from backend?)
│   └── export.py              # Export functionality
└── config/
    ├── __init__.py
    └── settings.py            # Configuration management
```

## Detailed Breakdown

### 1. **gui/components/** - UI Component Creation
**What goes here:**
- `_create_menu()`
- `_create_sidebar()`
- `_create_info_panel()`
- `_create_center_panel()`
- `_create_control_panel()`
- `_create_status_bar()`

**Benefits:**
- Each component is self-contained
- Easy to modify individual panels
- Can reuse components in other projects

**Example structure:**
```python
# gui/components/sidebar.py
class SidebarPanel:
    def __init__(self, parent, colors, callbacks):
        self.parent = parent
        self.colors = colors
        self.callbacks = callbacks
        self._create_widgets()
    
    def _create_widgets(self):
        # Sidebar creation code
        pass
```

### 2. **gui/dialogs/** - Dialog Windows
**What goes here:**
- `_on_connection_setup()` → ConnectionSetupDialog class
- `_on_adjust_parameters()` → ParameterAdjustDialog class
- `DebugConsole` class (already separate)

**Benefits:**
- Dialogs are independent windows
- Can be tested separately
- Easier to add new dialogs

### 3. **gui/graphs/** - Graph Management
**What goes here:**
- `_update_graphs()`
- Graph creation code from `_create_center_panel()`
- Graph styling and configuration

**Benefits:**
- Centralized graph logic
- Easy to add new graph types
- Can optimize graph updates independently

### 4. **hardware/** - Hardware Control
**What goes here:**
- `_initialize_motor_control()`
- `_send_motor_command()`
- `_wait_for_motor_position()`
- GPIO interrupt handling

**Benefits:**
- Hardware abstraction
- Easy to swap implementations (I2C, Serial, etc.)
- Can test without hardware

### 5. **measurement/** - Measurement Logic
**What goes here:**
- `_measurement_worker()` → MeasurementWorker class
- `_on_calibrate()` → CalibrationManager class
- Signal processing logic

**Benefits:**
- Core business logic separated
- Can test measurement logic independently
- Easier to add new measurement types

### 6. **data/** - Data Management
**What goes here:**
- `_create_measurement()`
- `_create_calibration()`
- `_get_measurements()`
- `_on_export()`

**Benefits:**
- Database operations centralized
- Easy to change storage backend
- Export logic separated

### 7. **config/** - Configuration
**What goes here:**
- `_load_connection_settings()`
- `_save_connection_settings()`
- Configuration validation

**Benefits:**
- Configuration logic isolated
- Easy to add new settings
- Can support multiple config formats

## Migration Strategy

If you decide to refactor, do it incrementally:

### Phase 1: Extract Hardware Control (Low Risk)
1. Create `hardware/motor_control.py`
2. Move motor control methods
3. Test thoroughly
4. Update imports in GUI.py

### Phase 2: Extract Data Operations (Low Risk)
1. Create `data/database_ops.py`
2. Move database methods
3. Test thoroughly

### Phase 3: Extract Dialogs (Medium Risk)
1. Create `gui/dialogs/` directory
2. Move dialog classes one at a time
3. Test each dialog

### Phase 4: Extract Components (Higher Risk)
1. Create `gui/components/` directory
2. Move UI creation methods
3. Refactor to use component classes
4. Test GUI thoroughly

### Phase 5: Extract Measurement Logic (Higher Risk)
1. Create `measurement/` directory
2. Move measurement worker
3. Refactor threading model
4. Test measurement workflow

## My Recommendation

### **For Your Current Situation:**

**Keep it as-is IF:**
- ✅ You're the only developer
- ✅ The code is working well
- ✅ You don't plan major changes soon
- ✅ You're close to project completion

**Refactor IF:**
- ✅ You plan to add significant features
- ✅ Multiple developers will work on it
- ✅ You want to improve testability
- ✅ You have time for careful refactoring
- ✅ Code is becoming hard to navigate

### **Minimal Refactoring (Best of Both Worlds):**

If you want some benefits without major restructuring:

1. **Extract DebugConsole** (already separate class - just move to own file)
2. **Extract Hardware Control** (low risk, high benefit)
3. **Extract Configuration** (low risk, cleaner code)

This gives you ~80% of the benefits with ~20% of the effort.

## Code Example: Minimal Refactoring

### Before (Current):
```python
# GUI.py (3092 lines)
class SPAMGui(tk.Tk):
    def _initialize_motor_control(self):
        # 75 lines of motor control code
        pass
    
    def _send_motor_command(self):
        # 50 lines
        pass
```

### After (Refactored):
```python
# hardware/motor_control.py
class MotorController:
    def __init__(self, settings, log_callback):
        self.settings = settings
        self.log = log_callback
        self._initialize()
    
    def send_command(self, motor_num, position):
        # Motor control logic
        pass

# GUI.py (now ~2900 lines)
from hardware.motor_control import MotorController

class SPAMGui(tk.Tk):
    def __init__(self):
        # ...
        self.motor_controller = MotorController(
            self.connection_settings,
            self._log_debug
        )
```

## Conclusion

**Short Answer:** Yes, splitting would be beneficial, but it's not urgent. The current code works fine.

**Best Approach:** 
- If you have time: Do a careful, incremental refactor
- If you're busy: Keep it as-is, it's not broken
- If you want quick wins: Extract hardware control and configuration only

**Key Principle:** Don't refactor working code unless you have a clear benefit or are adding significant features.

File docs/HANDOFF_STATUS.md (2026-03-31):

# HANDOFF_STATUS

Last updated: 2026-03-31
Scope: quick operator + new-agent handoff for current Pi/ADC state.

## Snapshot

### Done
- AD7193 SPI bring-up on Raspberry Pi is working.
- Driver-level conversion timeout issue resolved (ID check, mode clock bits, config alignment).
- GUI runs ADC-only measurement flow and logs live TX/RX updates.

### In Progress
- Team integration of calibrated voltage->S-parameter conversion for extraction accuracy.

### Blocked / Not Final Yet
- Final extraction fidelity on real hardware is blocked on teammate math merge.
- Motor/switch full-rig validation is pending when hardware is fully connected.

## Extraction Caveat (Current)

Current extraction path is operational but provisional: it can consume proxy S-parameters derived from ADC I/Q. Final-calibrated voltage->S conversion is pending teammate implementation.

## Verified Commands and Expected Signals

## 1) Low-level ADC check (Pi)

```bash
python - <<'PY'
from hardware import AD7193
adc = AD7193(spi_bus=0, spi_cs=0, speed_hz=100000, log_fn=lambda m,l: print(f"[{l}] {m}"))
adc.configure(gain=1, data_rate=96)
print("simulated =", adc.is_simulated)
for i in range(20):
    iv, qv = adc.read_iq()
    print(i, "I=", iv, "Q=", qv)
adc.close()
PY
```

Healthy behavior:
- `ID=0xA2 verified` (or any `0xX2` ID low nibble)
- no repeating `timeout reading ch0/ch1`
- finite, varying I/Q values

## 2) GUI run (Pi)

```bash
source venv/bin/activate
python app.py
```

Connection settings baseline:
- SPI bus `0`
- SPI CS `0`
- SPI speed `100000`
- ADC gain `1`
- ADC data rate `96`
- RF switch disabled (ADC-only)

Expected GUI log pattern:
- ADC initialized successfully
- no repeated ADC timeouts
- live measurement updates during run

## Immediate Next Steps (After Teammate Math Lands)

1. Add calibrated voltage->S conversion module at measurement/extraction boundary.
2. Replace proxy S reconstruction path with calibrated complex S11/S21 generation.
3. Re-run extraction against known reference sample and compare fit stability.
4. Lock default Pi settings (gain/rate/speed) based on measured SNR and runtime.
5. Update `README.md` and `REPO_CONTEXT.md` to remove provisional wording.

## Watchlist / Risks

- Calibration quality directly controls extraction trustworthiness.
- ADC-only tests (no motor) validate acquisition path, not full sweep mechanics.
- Wiring/contact quality can still cause intermittent field issues; keep a known-good wiring photo and settings baseline.

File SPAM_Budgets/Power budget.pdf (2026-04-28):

Component | Voltage req (V) | Current draw (A) | Power (W)
motor drivers (x8) | 9-42 | 4 | 36-
arduino mega | 7-12 | 0.05
raspberry pi | 5 | 3 | 15
RF Switches | 12 | 0.25 | 3
Gunn Diode Oscillator | 5 | 0.25 | 1.25
Load | Rail | Rated voltage | Max current | Idle current | Typical Current | Power consumption | max power
RF Switch | 28V | 30V | 90mA | - | 90mA | 2.52W | 90W
Motor driver | 28V | 9-42V | 5A | 0.26A | 0.6A | 14.4W | 120W
Servo motor | 7V | 7.4V | 3A | 0.1A | 0.8A | 7.4W | 2.2W
Raspberry Pi | 5V | 5V | 1.5A | 0.6A | 0.9A | 4.5W | 7.5W
Gunn diode | 5V | 5V | - | 10mA | 250mA | 1.25W
Amplifier | 5V | 5.5V | 35mA | - | 27mA | 0.081W | -
ESP32 | 5V | 3.3V | 400mA | 10mA | 120mA | 0.396W | 1.32W
ADC | 3.3V | 3.3V | 1mA | - | 0.85 mA | 0.0028W | 0.0033W

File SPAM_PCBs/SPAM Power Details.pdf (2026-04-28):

This will go over the schematics and layouts of the boards being used on the SPAM project’s final version as of Expo

Power Budget

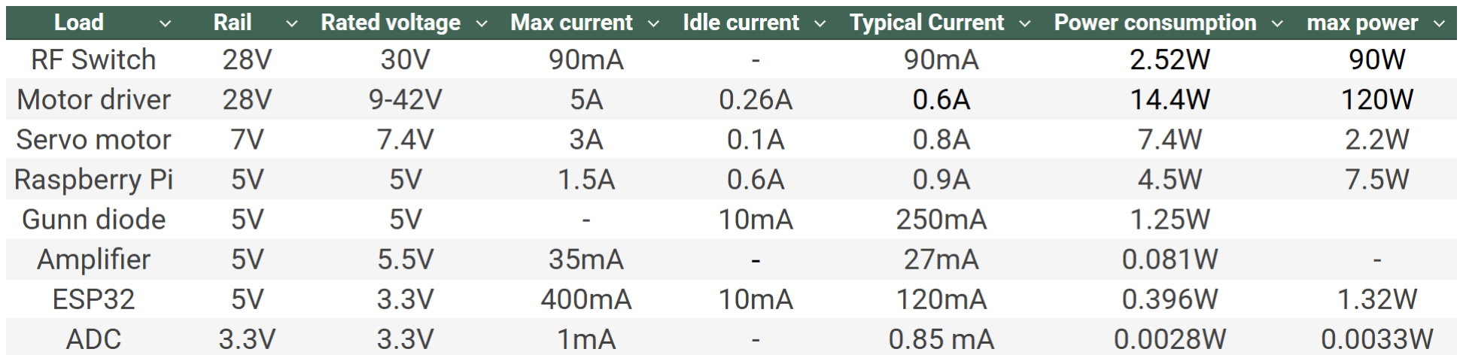
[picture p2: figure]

This table covers the expected power rating for each peripheral device interfacing with the power board. The data is taken from the components data sheets and used educated approximations where information was not available as is common in many datasheets. The segmentation of power requirements influenced the layout and performance requirements of the PCB board. All schematics and PCB files related to the project are on the github repo. All datasheets for items are in the budget file.

Power board

Schematic

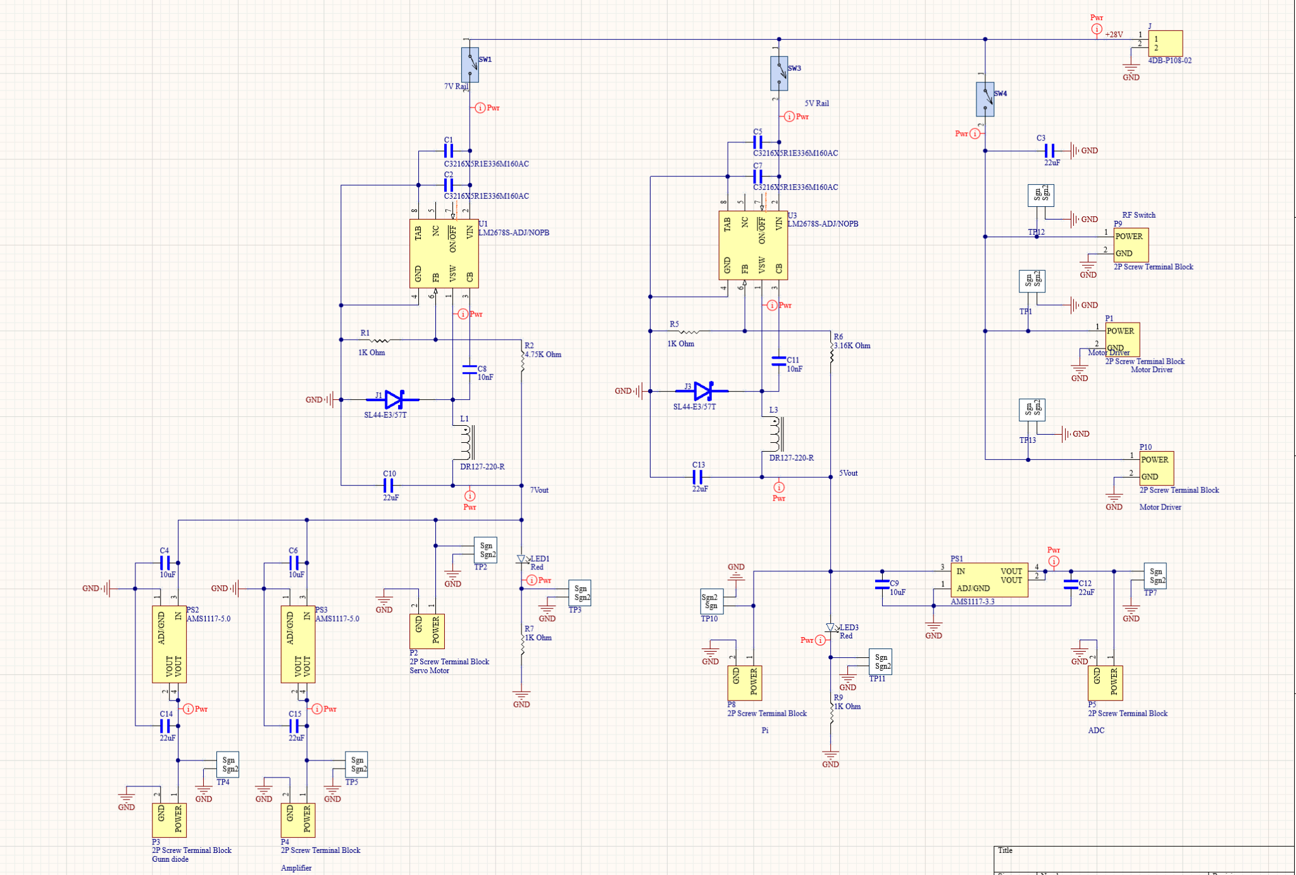
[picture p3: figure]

The power source was to be a 28V PSU connected to a wall outlet as the main feed to power the motor drivers and RF switch directly with the 28V. Each rail has a decoupling capacitor and a switch to selectively turn off/on power without disrupting the main PSU supply for easy debugging and isolation of problems.

There are 2 more rails each with the same adjustable buck converter package to step down the voltages. I chose this one for its wide voltage range and its high efficiency.

The resistor values for the rails were calculated using the aid of the buck converter datasheet and selecting them according to instructional guidance to achieve exact output levels as shown below.

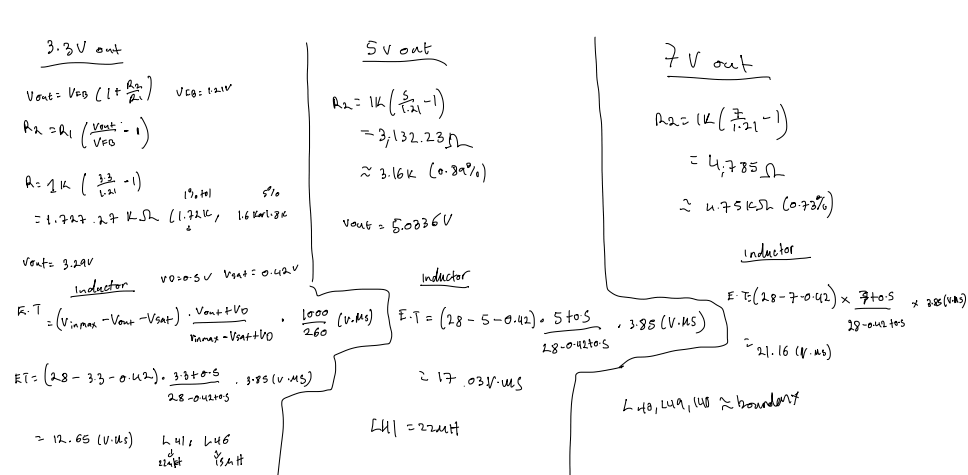
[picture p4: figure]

I also used capstone stocked LDOs to bring down the voltages from 5V to 3.3V for the ADC and 7V to 5V for the gunn diode and other RF. This is because the LDO has better line regulation and no switching noise so it's better for RF components since they require stable supplies to work properly. These are also fitted with both input at output capacitors to further improve signal integrity.

I used screw terminals for all outputs to interface with the peripherals since jumper cables seemed like the best way to have everything connected to the central board and a screw terminal strip for the PSU input with crocodile teeth connectors.

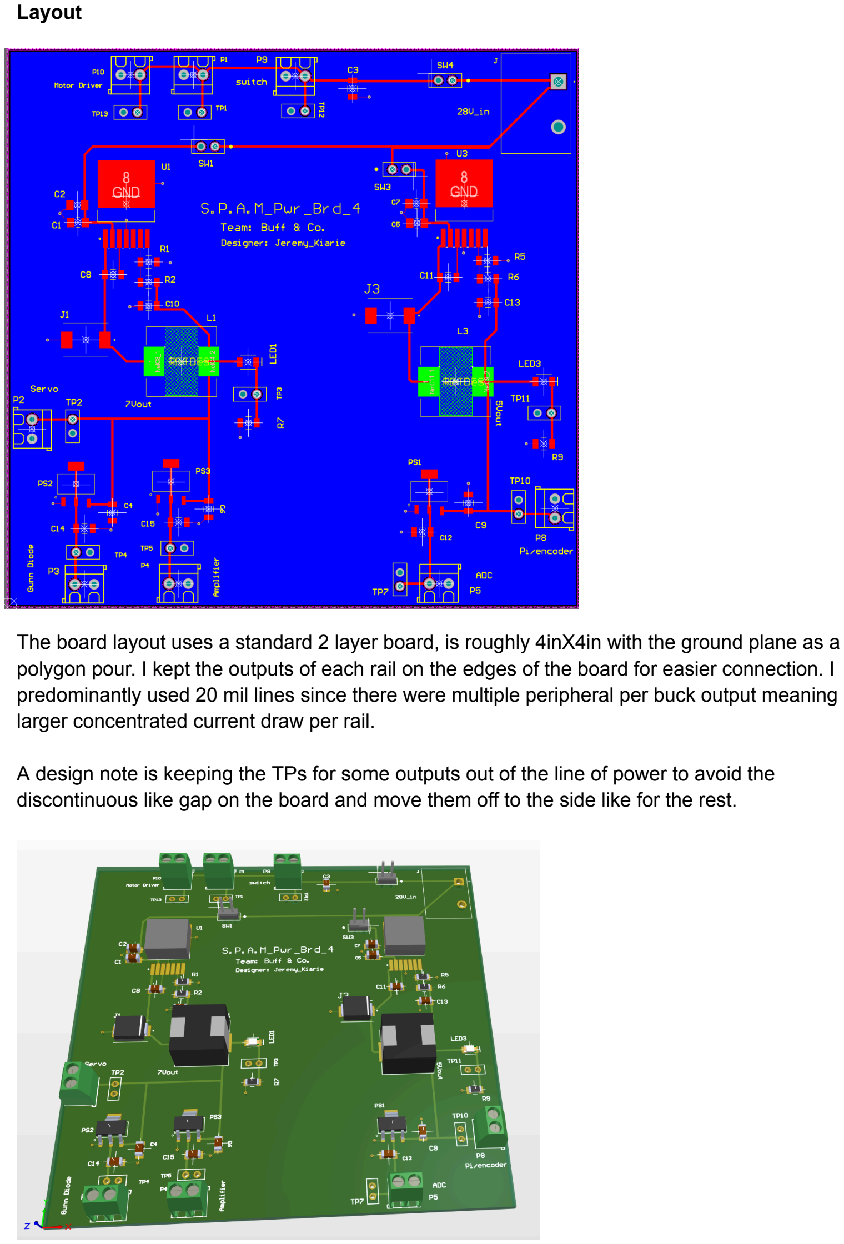
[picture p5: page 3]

Layout

The board layout uses a standard 2 layer board, is roughly 4inX4in with the ground plane as a polygon pour. I kept the outputs of each rail on the edges of the board for easier connection. I predominantly used 20 mil lines since there were multiple peripheral per buck output meaning larger concentrated current draw per rail.

A design note is keeping the TPs for some outputs out of the line of power to avoid the discontinuous like gap on the board and move them off to the side like for the rest.

ESP/Encoder board

Schematic

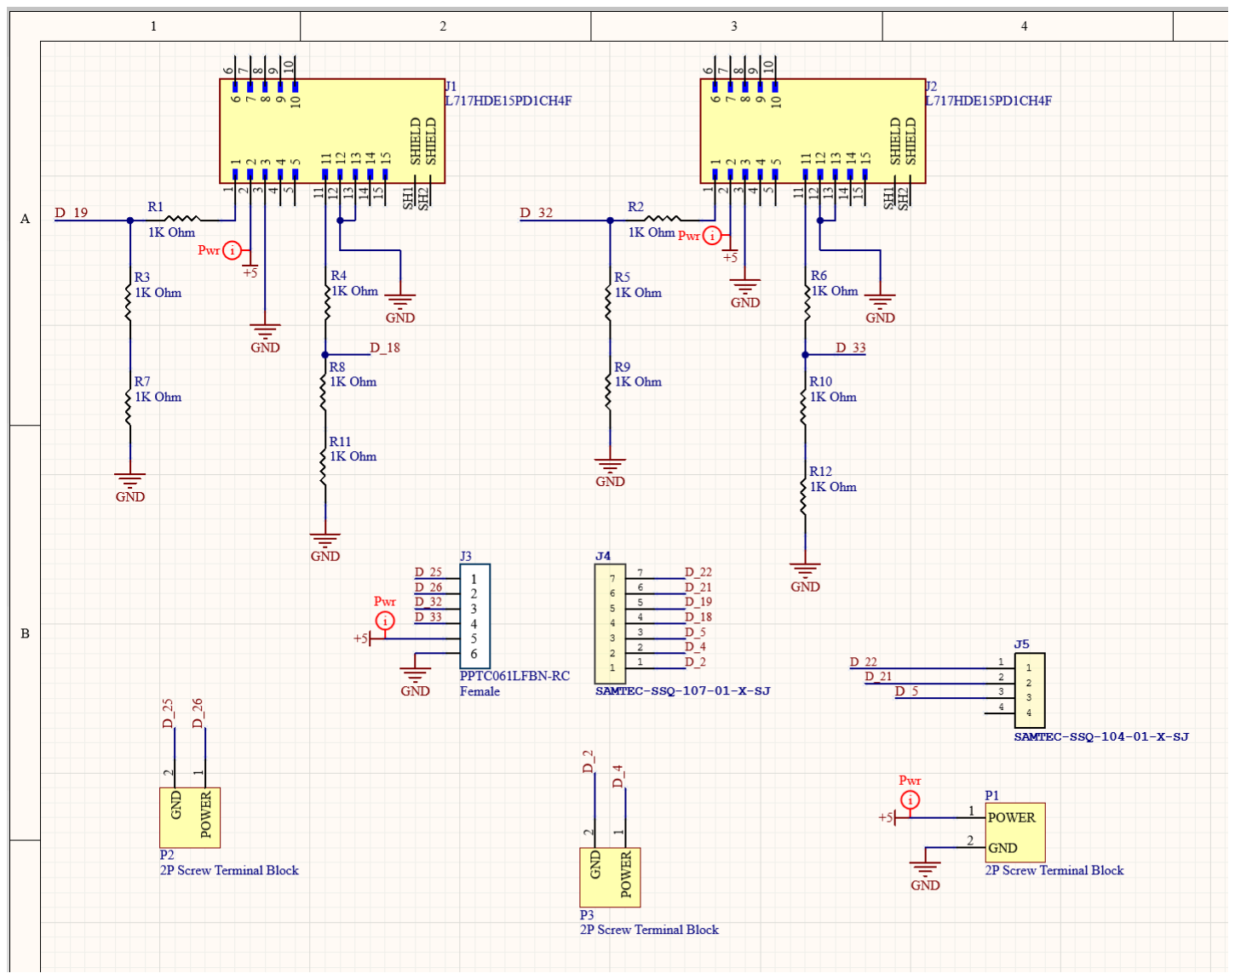
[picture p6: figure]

This is the layout for the board that powers the Pi, ESP and also allows communication to the arm motor encoders via the vga cables and gender changing connectors. The board is powered from the main power board via the 5V output which is what connects to the 5V inputs. Voltage dividers are used to supply collect logic levels and the header pins are used to connect to the pi and ESP.

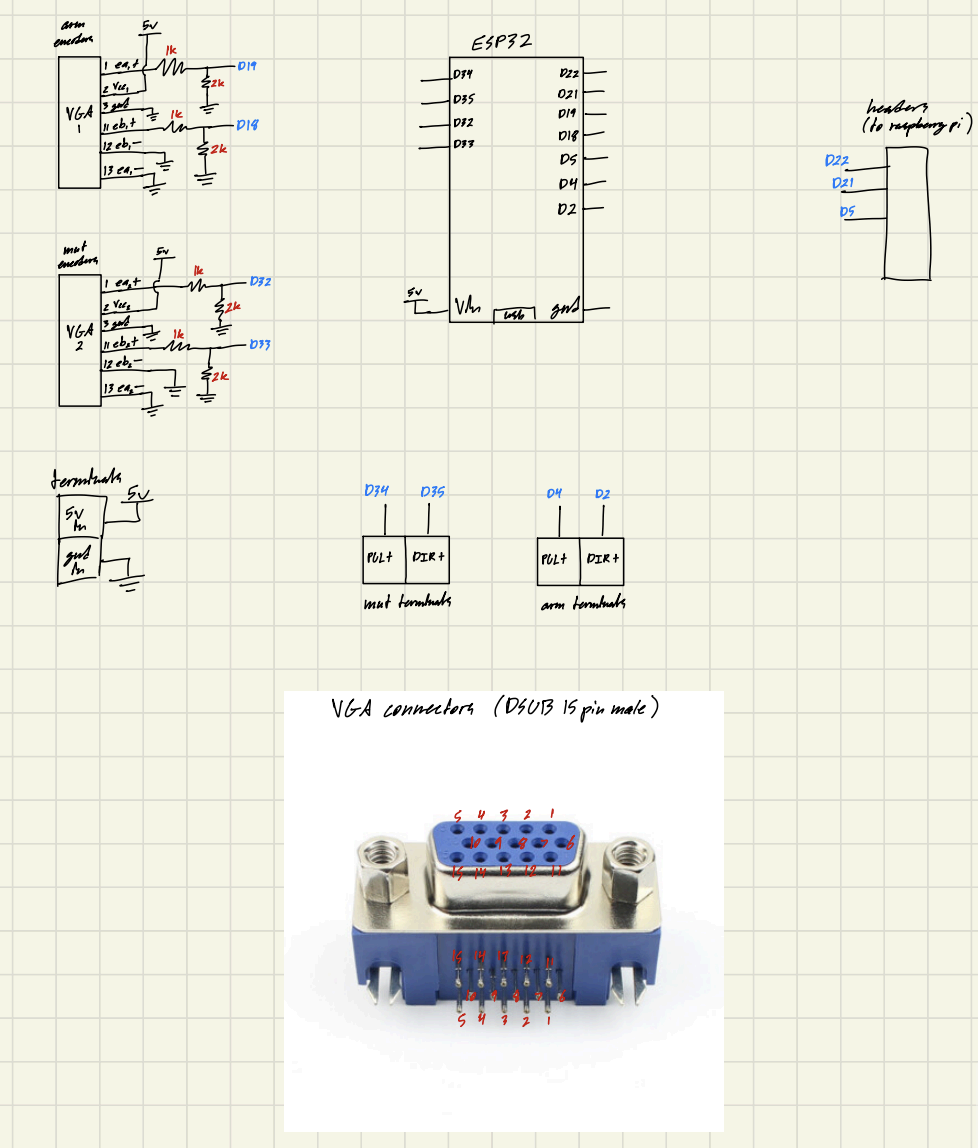
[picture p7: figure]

This was the design I was working off from Dillion Brown who was handling the firmware.

Layout

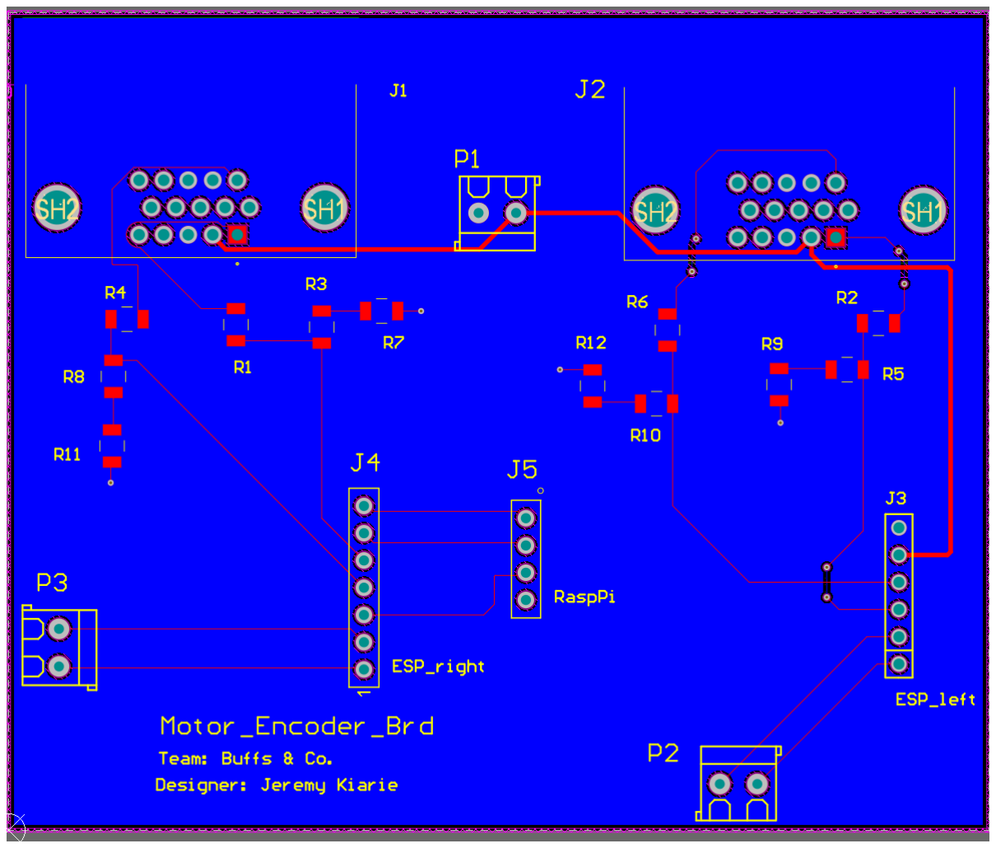
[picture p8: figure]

Standard 2 layer board and since it was mainly a signal board traces are kept small.

A progression would be orienting it so that the Pi can seamlessly connect onto it.

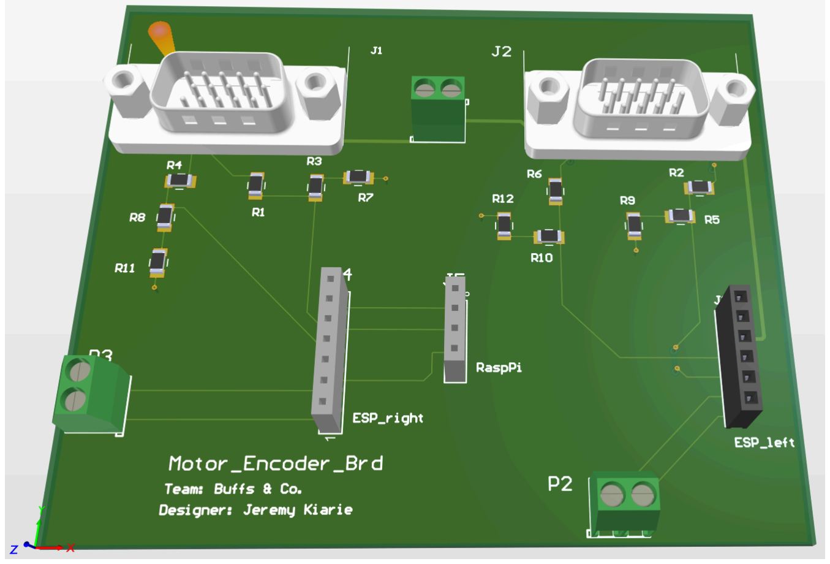
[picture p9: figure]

For footprints i used SnapMagic for almost all since it has Altium compliant versions and usually have good libraries with both models and footprints.

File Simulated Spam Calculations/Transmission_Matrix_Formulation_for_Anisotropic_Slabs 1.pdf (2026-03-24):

# Transmission Matrix Formulation for Anisotropic Slabs

## 1.Crystal Properties and Eigenvalue Problem

In an anisotropic electric and magnetic crystal, the modes satisfy the following eigenvalue problem

( | ) ( | ) | 0 | pm pe | D × | ×+ | = 1 | 0 |
- | | | | | | | | | | (0.1)
Where | 0 k kp =
, 1
m µr
− = , | 1
r e ε ⁻ = . For the scanner we enforce that | ˆ | ˆ ˆ | ˆ sin x | z | z p px pz | x pz = | + | = | + θ | . The incident
angle is set by the scanner while z p is yet to be determined
In a source-free region, | 0 | x

z

p ∇⋅ = → | =− D | D | D z | x p | . Ultimately, this implies that only the x and y component of
(1.1) are independent. Thus, our eigenvalue problem becomes

1 0 x

y

D
G
D
| + | = |
| (0.2)

Let

2 | zx | yz xy | xy yz
| yz yz
4 | xy | xy
yz | yz
xy | xy

1

3

5

6

2

x | xy | x y

y

| | zy
y | y
| y | y
| | x

y

x

m em
em em em
e m em
em e m
e m em
em m

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
= | − | −
−=

=

= | −
| −

=

= | −
yz | yz | xy zx | zx xy
xy | xy | yz zx | zx yz
yz | yz

xy xy

zx | yz xy | xy yz

yz yz

7

8

9

10

11

12

2 | 2
2 | 2

2

x | x
z | z
z | z
| y x

y

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

σ
σ
σ
σ
σ
σ
− | + | −
− | − | +
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
= | −

Then
( ) ( )²
3

2

1 | 2 sin | sin G | p | p xx | z = | + | + σ | σ | σ θ | θ z | (0.3)
4 | 5 | ( ) ² | sin G | p | p xy | z
= | +σσ | θ z | (0.4)
( | ( ) | ( ) | ( ) ) ² | 3 1 | 3 | 2
6 | 7 | 8 | 9 sin | sin | sin z
Gyx | p | z | z | z = σ | σ | θ | θ p | p | p + | + +σ | θ σ | (0.5)
( ) | ( )² ²
10 | 11 | 12 sin | sin Gyy | z | z =σ p | p + | + σ | θ | θ σ | (0.6)

This allows our polynomial coefficients to be written
( | ) ( ) ( | ) ( )
( | ) ( ) ( | ) ( )
( | ) ( )
( | ) ( )
4 | 2
0 | 3 12 | 5 9 | | 3 | 12
3
1 | 2 12 | 5 8 | 4 9 | 3 11 | 2 | 11
2
2 | 1 12 | 5 7 | 4 8 | 2 11 | 3 10 | 1 | 10
3 | 1 11 | 5 6 | 4 7 | 2 10
4 | 1 10 | 4 6
( ) | sin | sin | 1
( ) | sin | sin
( ) | sin
( ) | sin
()

A
A
A
A
A
θ σσ σσ | θ | σ σ | θ
θ σσ σσ σσ σσ | θ | σ σ | θ
θ σσ σσ σσ σσ σσ | θ σ σ
θ σσ σσ σσ σσ | θ
θ σσ σσ

−
−
= | | + | + | +
= | − | + | + | +
= | − | + | + | ++
= | − | − | +
−

−

=

(0.7)

such that
( ) | ( ) ( ) | ( ) | ( ) | ( ) ² | 3 | 4
0 | 1 | 2 | 3 | 4 0 | z | z | z | z | z = | = | + | + | + | + fp | A | A | p A | p A | p A | p θ | θ | θ | θ | θ | (0.8)
Note, we have enforced reciprocity (not lossless) in that | 1
m µr

− = and 1

r e ε ⁻ = are assumed to be symmetric tensors. Therefore, we have 12 unknowns we need to solve for
Unknowns: , , , , , , , , , , , , mmmm m m eeee e e x | y | z | xy | yz | zx x y z xy yz zx | (0.9)

The relation between the magnetic and electric flux densities within the slab can be written in the spectral domain as
B | p eD = | × η0 ( | ) | | (0.10)

## 2. SPAM S-Parameter to Transmission Matrix

The scattering matrix measure by the SPAM system is in the h-v (horizontal/vertical) coordinate system (make figure for this) such that

11 | 11 | 12 | 12
1 | 1 | 1
11 | 11 | 12 | 12
1 | 1 | 1 11 | 12
21 | 21 | 22 | 22
2 | 2 | 2 21 | 22
21 | 21 | 22 | 22
2 | 2 | 2
h | hh | hv | hh | hv | h | h
v | vh | vv | vh | vv | v | v
h | hh | hv | hh | hv | h | h
v | vh | vv | vh | vv | v | v
E | S | S | S | S | E | | E
E | S | S | S | S | E | SS | E
E | S | S | S | S | E | SS | E
E | S | S | S | S | E | | E
− | + | +
− | + | +
− | | | | | + | | +
− | + | +
- | | | | | | = | = | | | | | | | |

(0.11)

We wish to formulate our problem in the coordinate system of the material (xyz) such that

11 | 11 | 12 | 12
1 | 1 | 1
11 | 11 | 12 | 12
1 | 1 | 11 | 12
21 | 21 | 22 | 22
2 | 2 | 21 | 22
21 | 21 | 22 | 22
2 | 2
x | xx | xy | xx | xy | x | x
y | yx | yy | yx | yy | y
x | xx | xy | xx | xy | x
y | yx | yy | yx | yy | y
E | S | S | S | S | E | E
E | S | S | S | S | E | SS
E | S | S | S | S | E | SS
E | S | S | S | S | E
− | + | +
− | +
− | +
− | | | | | +
- | ′ | ′ | ′ | ′ | | | | ′ | ′ | ′ | ′ | | ′ | ′ | | | = | = | | ′ | ′ | ′ | ′ | | ′ | ′ | | | | ′ | ′ | ′ | ′ | | | | |

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
(0.12)

These can be easily related to one another by noting 1,2; | 1,2; cos E | E x | h | θ ± | ± = | and E | E 1,2; | 1,2; y | v
± | ± =

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

If we define a normalized transmission matrix such that | , | ,
0 | 0
L | R
t | t
| eL | eR
E | | E
T
η | η J | J
- | | | = ′ | | | | | |
- | | , then we have
10 | 0 | 0 | | | | | 1 10 | 0 | 0
01 | 0 | 0 | 11 | 12 | 21 | 22 | 01 | 0 | 0
0 0 sec | 0 | 0 0 cos | 0
11 | 12 | 21 | 22 0 0 | 0 | cos | 0 0 | 0 | sec
| | | S | S | S | S
T
S | S | S | S θ | θ
θ | θ

−

−
−
- | | | + | + ′ | ′ | ′ | ′ | ′ = | | | | | | − | − | − | − ′ | ′ | ′ | ′ | | | | | | |
I I
I | I | (0.20)

Thus, we now have a matrix from measurement which relates the fields at the input and output of the slab. The next step is for us to examine the relation between the ABCD matrix above and the modes within the slab.

## 3.Converting Material to Theoretical Transmission Matrix

The field at any point within the slab can be described by a superposition of its four modes.

1

1 | 2 | 3 | 4 | 1 | 2 | 3 | 4 | 2
1 | 2 | 3 | 4
1 | 2 | 3 | 4 | 1 | 2 | 3 | 4 | 3
| | | | | | | | 4
t | t | t | t | t | t | t | t | t
t | t | t | t | t | t | t | t | t
D | D | D | D | D | DDDD
B | B | B | B | B | BB | B | B

α
α
α | α | α | α
α
α
= | + | + | + | = | | | | | | | | | | |
- | | | | | | | | | (0.21)

Where the subscript t refers only to the tangential components (x and y) of the D or B . The eigen vectors are obtained by solving the dispersion relation and then enforcing (1.2) and (1.10). We will use the relation in (1.21) to relate the tangential fields at the output to the tangential fields at the input (and thus obtain an ABCD matrix).
At the second (right) side the slab, we have that out,R | in,R | out,R | | | | | | | | | in,R
tan | tan | tan | tan E | E | H | H = | , | = | | | . Recall that
in | in | in | in
0 | 0 ε | µ E | eD | H | mB = | , | = | | | | . Therefore,

in

0 | 1 | 2 | 3 | 4 ε | α E | eDDDD = | ,,, |
- | | (0.22)
However, since the D field for each mode is solenoidal (∇⋅ = D 0 ), | x
iz | ix
zi
p D | D
p = − | , we have that
0 | 0

0

| 10 | | 10
100
| 01 | | 01
010
- | 0 | - | 0
10
100 , | 01
010
- 0
x | x
zi | zi

x
zi
i | i | ti | ti | ti
p | p
p | p
ti | i ti | i
p
p
E eD e | D | E | e | D
E eD e | e
ε | ε

ε

= | = | → | = | | | | | | | | | | | | |
→ | = | | | | | | |

(0.23)

Thus, if we define

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

## 4. Algorithmically Computing the T-matrix from Material

Going back again to our eigenvalue problem, we can write this in matrix form as
1
0
1
xx | xy | x
yx | yy | y
G | G | D
G | G | D
- | + | | = + |
(0.29)

In MATLAB (or other computational tool), the roots of the polynomial in (1.8) can be computed as
p | AAAAA z = roots , , , , ( 4 | 3 | 2 | 1 | 0 ) | (0.30)

Where now z p is the array containing all four roots of (1.8). The matrix Λ is now given by
( | ) ⁰ diag | z jk p d Λ = | e | . | (0.31)

To compute the modes, we note from (1.29) that
( | )
( | )
( | ) ( | )
1 | 1
0
1 | 1
1 | 1
i | i | i | i i | i | i | xx | x | xy y xx | xy | x
i | i | i | i | i | i | i yx | yy | y | yx x | yy | y
i | i | i | i | i | i
xx | yx | x | yy | xy | y
G | G | D | G | D | GD
G | G | D | GD | G | D
GG | D | GG | D
- | + | | + | =−
- = →
| + | − | = | +
→ | − | + | = | − | +

(0.32)

which is satisfied when

1, | 1 i | i | i | i | i | i DG G | DG G x | yy | xy
= | − | + | = | − | +
y | xx | yx | . | (0.33)

This describes the electric flux density of the mode. The magnetic flux density is then

0 | 0 ( | )
0 | 0

10
01
- 0
, | 0- | 0
, | 0-
0 | 0 ,

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
x | xy | zx | i
i | i | x
i | i | xy | y | yz | i
y p
zx | yz | z | p
p | i x | zx | xy p | i | z
p | x | i
i | xy | yz | y p | i | z | x
y p | x zx | z | yz p

ee e
D
B | p eD | p e | e e | D
ee | e
e | e | e | p D
pe | e | e | p | p D
p e | e | e
η | η
η | η
= | × | = | × | | | | | | | |
- | − | | | | |
= | × | − | = | | | | − | | |

( | )
( | ) ( | )
( | )

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
x | x
zi | zi

x
zi

p
x | zx | xy p | i
p | x
xy | yz | y p | i
y p
zx | z | yz p
i | i p
z | xy | yz p | z y
i
i | i p | p | x
z | x | zx | x | zx | z | z xy | x yz p | p | i
y
p
x | xy | yz p | x y
e | e | e
D
e | e | e
D
e | e | e
p e | e | pe
D
p e | e | p e | e | pe pe | D
p e | e | p e

η

- | − | | − | | | − |
- | − | = | − | − | − | − | − |

(0.34)

This confirms (as a sanity check) that | x zi
i | p B | B z | x p = − | . From the expression above, we can write the x and y
components of the magnetic flux density as

( | )
( | ) ( | )

0

0

1

1 | x zi
i | i | i | i | i
x | x yz | z xy | x | z y y
i | i | | p | | i | i | i | | i
y | z x | x zx | p | x z | z zx | x | z xy | x yz | y
B | pe pe D peD
B | pe pe | pe pe D | pe pe D

η

η

= | − | −
= | − | + | − | + | − | | | | | |

(0.35)

To obtain the electric/magnetic intensities for each mode, we need to compute i e and mi

, 10 | 10
100 | 100 | 100
01 | 01 | , 010 | 010 | 010
- | 0 | - | 0 | ,
,

x
zi

x
zi
x | x | x
zi | zi | zi

x
zi

p
x | zx | xy p x | xy | zx
p
i | xy | y | yz | xy | yz | y p
p | p | p zx | yz | z p | p | zx | z | yz p

p
x | zx | xy p

xy

e | e | e ee e
e | e | e | ee | e | e | e
ee | e | e | e | e
e | e | e
e
- | | | | | − | | | | | | | | | | | | = | | = | | − | | | | | | | | | | | | | | | | | | | | | | | | − |

− =

, x

zi

p
p | yz | y e | e
- | − |

(0.36)

Therefore
, | , , , | ,
x | x
zi | zi
x | x
zi | zi
p | p
x | zx | xy p | p x | zx | xy
i | i p | p
xy | yz | y p | p xy | yz | y
e | e | e | m | m | m
e | m
e | e | e | m | m | m
- | | | − | − = | | | = − | − | | |
- | | (0.37)
Thus, the modal quantities for electric field intensity, | 0
1 E | eD ti | i ti ε = | , are
0 | 0 ( | ) | , | , ( | ) x | x
zi | zi
i | p | p i | i | i | i | i E | e | e D e D | E | e | e D eD x | x | zx | x | xy y p | p y | xy | yz | x | y y ε | ε = | − | + | = | − | + | (0.38)
The modal quantities for the effective current, | 0
1 ˆ | ˆ e
ti | i ti J | z H | z | mB
µ
=− × | =− × | | , are then

0

0

0

1

0 | 1
01 | , | ,
-1 0 | , | ,
,
,
x | x
zi | zi
x | x
zi | zi

x
zi

x
zi
p | p ei | i | i x | zx | xy p | p xy | yz | y x | x | x
ei | p | p i | i
y | y | y xy | yz | y p | p | zx | x | xy
p | i
xy | yz | y p | x
p | i
p | zx | x | xy | y
J | B | B m | m | m | m | m | m
J | B | B m | m | m | mm | m
m | m | m | B
mm | m | B

η

η

µ

η

- | | | | − | − | = | | | | = | | | | | − | | − | − | | | |
- | − | | = | | − | − | | | |

(0.39)

Therefore

( | ) | ( | ) 0 | 0 | 0 | 0 | 0 | 0
1 | 1 ,
i | i i | i x | x | y | y x | x
zi | zi
ei | p | B | B | B ei | p | B
c | p x | xy | yz | y | c | p y | zx | x | xy J | m | m | m | J | mm | m η | η | η | η
= | − | + | = | − | − | (0.40)

Let’s rearrange the units a little bit to make it more convenient
( | ) | ( | ) 0 | 0 | 0 | 0
, | ,
i | i i | i x | x | y | y x | x
zi | zi
i | i p | D | D | D p | D E | e | e | e | E | e | e | e x | x | zx | xy = | − | + | = | − | + p | p ε | ε | y | xy | yz | ε | ε y | (0.41)
0 | ( | ) 0 | 0 | 0 | ( | ) 0 | 0 , x | x
zi | zi
ei | p | p i | i | ei | i | i
x | xy | yz | x | y | y | y p | p | zx | x | x | xy | y η | η J | m | m cB mcB | J | m m cB m cB = | − | + | = | − | − | (0.42)

( | )
( | ) ( | )
0 | 0
0 | 0

0

0

i i
x | y
i i x | x | y

zi

i | i | i D | D
x | x yz | z xy | | z y
i | i | p | D i | i | D
y | z x | x zx | p | x z | z zx | z xy | x yz
cB | pe pe | pe
cB | pe pe | pe pe | pe pe
ε | ε
ε | ε
= | − | −
= | − | + | − | + | − | | | | | |

(0.43)

Since eigenvectors can include an arbitrary constant, we redefine them such that

0 | 0
1, | 1 i i Dx | i | i | Dy | i | i
ε | ε = | − | + | = | − | + GG | GG yy | xy | xx | yx | (0.44)

Let us define a normalized transmission matrix T′ such that

1
, | , | ,
0 | 0 | 0
L | R | R
t | t | t
eL | eR | eR
E | E | E
T | VV
η | η | η J | J | J
− | | | | | = | = Λ ′ | ′′ | | | | | | | | | |
- | | | (0.45)

This will ultimately be compared to a measured normalized transmission matrix computed as

10 | 0 | 0 | 1 10 | 0 | 0
01 | 0 | 0 | 11 | 12 | 21 | 22 | 01 | 0 | 0
0 0 sec | 0 | 00cos | 0
11 | 12 | 21 | 22 0 0 | 0 | cos | 0 0 | 0 | sec
S | S | S | S
T
S | S | S | S θ | θ
θ | θ
− | | | + | + ′ | ′ | ′ | ′ | ′ = | | | | | | − | − | −+ ′ | ′ | ′ | ′ | | | | | | |
I I
I | I | (0.46)

## 5. Summaries

Theoretical to T Matrix
Given material parameters, we can build a T matrix by first computing the A coefficients in (1.8) and the G matrix in (1.3) through (1.6) and then computing (in this order)
p | AAAAA z = roots , , , , ( 4 | 3 | 2 | 1 | 0 ) | (0.47)
( | ) ⁰ diag | z jk p d Λ = | e | (0.48)
0 | 0
1, | 1 i i Dx | i | i | Dy | i | i
ε | ε = | − | + | = | − | + GG | GG yy | xy | xx | yx | (0.49)
( | ) | ( | ) 0 | 0 | 0 | 0
, | ,
i | i i | i x | x | y | y x | x
zi | zi
i | i p | D | D | D p | D E | e | e | e | E | e | e | e x | x | zx | xy = | − | + | = | − | + p | p ε | ε | y | xy | yz | ε | ε y | (0.50)
( | )
( | ) ( | )
0 | 0
0 | 0

0

0

i i
x | y
i i x | x | y

zi

i | i | i D | D
x | x yz | z xy | | z y
i | i | p | D i | i | D
y | z x | x zx | p | x z | z zx | z xy | x yz
cB | pe pe | pe
cB | pe pe | pe pe | pe pe
ε | ε
ε | ε
= | − | −
= | − | + | − | + | − | | | | | |

(0.51)

0 | ( | ) 0 | 0 | 0 | ( | ) 0 | 0 , x | x
zi | zi
ei | p | p i | i | ei | i | i
x | xy | yz | x | y | y | y p | p | zx | x | x | xy | y η | η J | m | m cB mcB | J | m m cB m cB = | − | + | = | − | − | (0.52)
1 | 2 | 3 | 4
1 | 2 | 3 | 4
1 | 2 | 3 | 4
0 | 0 | 0 | 0
1 | 2 | 3 | 4
0 | 0 | 0 | 0
x | x | x | x
y | y | y | y
e | e | e | e
x | x | x | x
e | e | e | e
y | y | y | y
E | E | E | E
E | E | E | E
V
J | J | J | J
J | J | J | J

ηηηη
ηηηη
′
- (0.53)
1 T VV ⁻ ′ | ′′ = Λ | (0.54)
Summary – Measurement to T Matrix
After taking measurements with the SPAM system in the h-v coordinate system we perform computations in the following order to obtain the normalized transmission matrix
cos 0 | 0 | 0 | sec 0 | 0 | 0
11 | 12 | 0 | 1 | 0 | 0 | 11 | 12 | 0 | 1 | 0 | 0
0 | 0 cos 0 | 0 | 0 sec 0
21 | 22 | 0 | 0 | 0 | 1 | 21 | 22 | 0 | 0 | 0 | 1
S | S | S | S
S | S | S | S
θ | θ
θ | θ
- | | | | | | ′ | ′ | | | = | | |
′ | ′ | | | | | |

(0.55)

10 | 0 | 0 | | | | | 1 10 | 0 | 0
01 | 0 | 0 | 11 | 12 | 21 | 22 | 01 | 0 | 0
0 0 sec | 0 | 00cos | 0
11 | 12 | 21 | 22 0 0 | 0 | cos | 0 0 | 0 | sec
| | | S | S | S | S
T
S | S | S | S θ | θ
θ | θ
− | | | + | + ′ | ′ | ′ | ′ | ′ = | | | | | | − | − | −+ ′ | ′ | ′ | ′ | | | | | | |
I I
I | I | (0.56)

## 6. Simulated Test Cases

An HFSS simulation will provide generalized (power-wave) scattering parameters. To convert from these to electric-field scattering parameters:

TM

TE

TM

TE

1
2
2 TM
1
2 | 2 11 | 12 | TE | 11 | 12
2 | 1 TM 21 | 22 | 21 | 22 | 2
2 TE | 1
2
0 | 0 | 0
0 | 0 | 0
0 | 0 | 0 | 0 | 0 | 0
0 | 0 | 0 | 0 | 0 | 0
0 | 0 | 0
0 | 0 | 0
| | | Z
Z
| Z | | | Z
| Z | | | Z
| | Z
| | | | | Z
SS | SS
SS | SS
- | | | | | | ′ | ′ | | | = | | | ′ | ′ | | | | | | | | | | |

(0.57)

10 | 0 | 0 | | | | | 1 10 | 0 | 0
01 | 0 | 0 | 11 | 12 | 21 | 22 | 01 | 0 | 0
0 0 sec | 0 | 0 0 cos | 0
11 | 12 | 21 | 22 0 0 | 0 | cos | 0 0 | 0 | sec
| | | S | S | S | S
T
S | S | S | S θ | θ
θ | θ
− | | | + | + ′ | ′ | ′ | ′ | ′ = | | | | | | − | − | −+ ′ | ′ | ′ | ′ | | | | | | |
I I
I | I | (0.58)

Five materials slabs have been simulated so far and converted into scattering parameters that would hypothetically be given by the SPAM system. Each material is 60 mil thick and illuminated over angles between 2 and 88 degrees in steps of 2 degrees. I have already taken the HFSS files and converted them into S’ using (1.57). The files for each material sample are named with the prefix SPAM_Scat_Mat_*. The material parameters corresponding to each file suffix are given below
200 | 300
er2_mur3 | 0 2 0 , | 0 3 0
002 | 003
r | r ε | µ
↔= | = | | |
- | | ,
200 | 300
er225_mur333 | 0 2 0 , | 0 3 0
005 | 003
r | r ε | µ
↔= | = | | |
| 200 | 300
er225_mur343 | 0 2 0 , | 0 4 0
| 005 | 003
r | r ε | µ
↔= | = | | |
- | | ,
201 | 300
er201205_mur343 | 0 2 0 , | 0 4 0
105 | 003
r | r ε | µ
↔= | = | | |
( ) | ( )
| 201 | | 300
er201205_allj_mur343_allj | 0 2 0 1 | , | 0 4 0 1
| 105 | | 00 3
r | r ε | µ j | j
↔= | − | = | − | | |

I have written a code which compares the normalized transmission matrices to their theoretically computed counterparts. There is something off between the Transmission matrices (which I believe originates from disagreement in the eigenvector computation since the eigenvalues seem to agree quite well aside from a mysterious sign).
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

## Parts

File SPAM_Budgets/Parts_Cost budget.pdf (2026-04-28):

Item | Supplier | Url | Quantity | Total cost | Notes | Capstan Drive BOM Mixer | Mini circuits | https://www. minicircuits. com/WebStore/dash
1 | $491.34 | Arrived | Name of Component | Quantity | Price Mech stuff | Amazon/ebay | 16 | $133.59 | Arrived | Rope -- 1m | 5 | $3.85) | need quantity 5 to have 5 meters, comes in lenghts of 1, 31 etc.
Steppers | Maker Store | 0 | $0.00 | Returned | 40x50x6mm Bearing (https://www.amazon.com/dp/B085NDM5WV?ref=ppx_yo2ov_dt_b_product_details&th=1) | 2 | $17.58) Amplifier | Digikey | https://www.digikey.com/en/products/detail/qorvo/CMD298C4/24611270 1 | $0.00 | Returned | 3x10x4mm Bearings (30cnt) | 1 | $6.99) Cobham Switch eBay | https://www.ebay.com/itm/265076885998 1 | $129.95 | Arrived | 15x28x7mm Bearing (8cnt) | 1 | $9.99)
Raspberry Pi | Adafruit | https://www.adafruit.com/product/4296 1 | $73.82 | Arrived | M3 x 6mm Inserts (https://www.amazon.com/gp/product/B07LBQRYR3/ref=ppx_yo_dt_b_search_asin_title?ie=UTF8&psc=1) | 1 | $8.49) WG-Coax Adapter Hasco componentshttps://www.hasco-

inc. com/adapters/adapt

2 | $876.56 | Arrived | M3 x 5mm Hex Standoffs (https://www.amazon.com/DTGN-M3x5mm-DXL-Standoff-Electronic/dp/B0BC8X9CPK) | 1 | $7.99)

25KG Digital Servo Motor Amazon

https://www. (https://www.amazon.com/Torque-Motors-Waterproof-Steering-Control/dp/B0DDKN9RS6) amazon. (https://www.amazon.com/Torque-Motors-Waterproof-Steering-Control/dp/B0DDKN9RS6) com/Torque-Motors-
2 | $27.98 | Arrived | M3 x 10mm Hex Standoffs | 1 | $13.99)

Fairview SwitchFairview Mircowave (https://www.fairviewmicrowave.com/product/spdt-failsafe-26.5-ghz-electro-mechanical-relay-switch-90w-28v-sma-fmsw6421.html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)https://www.
fairviewmicrowave. (https://www.fairviewmicrowave.com/product/spdt-failsafe-26.5-ghz-electro-mechanical-relay-switch-90w-28v-sma-fmsw6421.html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) com/product/spdt-
1 | $439.98 | Arrived | M3 Locknuts (https://www.amazon.com/100Pcs-Stainless-Self-Lock-Inserted-Clinching/dp/B075ZZW7VL) | 1 | $6.99) Amplifier | Analog Devices Inc/digikey https://www.digikey.com/en/products/detail/analog-devices-inc/EV1HMC1131LC4/5886923 1 | $383.25 | Arrived | M3 x 6mm Screws | 1 | $7.99)
Power stuff | Digikey | 50 | $61.98 | Arrived | M3 x 10mm Countersunk Screws (https://www.amazon.com/dp/B07DWVDDWC?psc=1&ref=ppx_yo2ov_dt_b_product_details) | 1 | $5.99)
Rotary EncoderAmazon | https://www.amazon.com/Photoelectric-Incremental-Encoder-DC5-24V-Optical/dp/B0DS5Q5649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 (https://www.amazon.com/Fullerkreg-Socket-Stainless-Machine-Quantity/dp/B07CK3RSN3) 1 | $15.99 | Arrived | M3 x 10mm Screws (https://www.amazon.com/Fullerkreg-Socket-Stainless-Machine-Quantity/dp/B07CK3RSN3) | 1 | $6.99) WG-Coax Adapter Hasco componentshttps://www.hasco-
| | inc. com/adapters/adapt
| | 1 | $430.55 | Arrived | M3 x 45mm Screws (https://www.amazon.com/dp/B089KRYJ9Q?psc=1&ref=ppx_yo2ov_dt_b_product_details) | 1 | $7.69)
VGA Cable (Esp Brd) Digikey | https://www.digikey.com/en/products/detail/amphenol-cs-commercial-products/L717HDE15PD1CH4F/4886538 4 | $15.58 | Arrived | M3 x 55mm Screws (https://www.amazon.com/dp/B0BGM9N73R?ref=ppx_yo2ov_dt_b_product_details&th=1) | 1 | $9.66)
VGA connector (ESP Brd) Ebay | https://www.ebay.com/itm/115859852615?itemid=115859852615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 (https://www.amazon.com/gp/product/B08LMNFS5P/ref=ewc_pr_img_1?smid=A7L3QGQ9OUIWY&psc=1) 4 | $18.22 | Arrived | M4 Locknuts (https://www.amazon.com/gp/product/B08LMNFS5P/ref=ewc_pr_img_1?smid=A7L3QGQ9OUIWY&psc=1) | 1 | $4.99)
800 0hm res | Digikey | https://www.digikey.com/en/products/detail/yageo/RC1206FR-07806RL/729127 10 | $7.11 | Arrived | M4 x 14mm Screws (https://www.amazon.com/M4x12mm-M4-0-7x12mm-Stainless-Machine-Quantity/dp/B0CLGWZSLT) | 1 | $8.89)
LPF Sma connector Digikey | https://www.digikey.com/en/products/detail/te-connectivity-linx/CONSMA002-SMD/1577205 4 | $24.07 | Arrived | M4 x 25mm Screws (https://www.amazon.com/M4-0-70-Button-Stainless-Fullerkreg-Plastic/dp/B07H17FB12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) | 1 | $8.89)
$3,129.97 | M4 x 30mm Screws (https://www.amazon.com/M4-0-70-Button-Stainless-Fullerkreg-Plastic/dp/B07H146QMW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) | 1 | $8.89) M4 x 70mm Screws | 1 | $8.69)
Total Cost | ($ 136.96)
Power parts | model | Manufacterer | number | url | cost
Buck (24-3.3 Adj) LM2678S-ADJ/NOPB-ND T.I | | | 6 | https://www.digikey.com/en/products/detail/texas-instruments/lm2678s-adj-nopb/363826 49.44
screw terminal | 4DB-P108-02 | TE Connectivity AMP | 2 | https://www.digikey.com/en/products/detail/te-connectivity-amp-connectors/4DB-P108-02/1277921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 3.92
buck Schottky Diode SL44-E3/57T | Vishay | 6 | https://www.digikey.com/en/products/detail/vishay-general-semiconductor-diodes-division/SL44-E3-57T/1091493 3.3
buck Inductor | DR127-220-R | Eaton | 6 | https://www.digikey.com/en/products/detail/eaton-electronics-division/DR127-220-R/667170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 4.92
33 uF cap | C3216X5R1E336M160AC TDK Corporation | | 12 | https://www.digikey.com/en/products/detail/tdk-corporation/C3216X5R1E336M160AC/2792259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 8.47
4.7k ohm Res | RC0402JR-074K7L | Stackpole Electronics Inc | 6 | https://www.digikey.com/en/products/detail/stackpole-electronics-inc/RMCF1206JT4K70/1753837 0.6
3.16k ohms Res | RC1206FR-073K16L | YAGEO | 6 | https://www.digikey.com/en/products/detail/yageo/RC1206FR-073K16L/728760 0.6
1.74k ohm Res | RC1206FR-071K74L | YAGEO | 6 | https://www.digikey.com/en/products/detail/yageo/RC1206FR-071K74L/728462 0.6
VGA | L717HDE15PD1CH4FAmphenol ICC | | 4 | https://www.digikey.com/en/products/detail/amphenol-cs-commercial-products/L717HDE15PD1CH4F/4886538 8.88
| | | | | 80.73
| | | 54 | after shipping | 86.95

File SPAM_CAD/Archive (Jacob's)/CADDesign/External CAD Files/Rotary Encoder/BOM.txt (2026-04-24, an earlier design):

3DX_Same_Sky_Supplier: Same Sky
3DX_Same_Sky_Description: AMT10 Radial, Fixed Resolution, 2048 PPR, 8 Index Pulses, 5 mm Bore, Standard, Incremental, Capacitive Modular Encoder
3DX_Same_Sky_Model Number: AMT102-2048-N5000-S

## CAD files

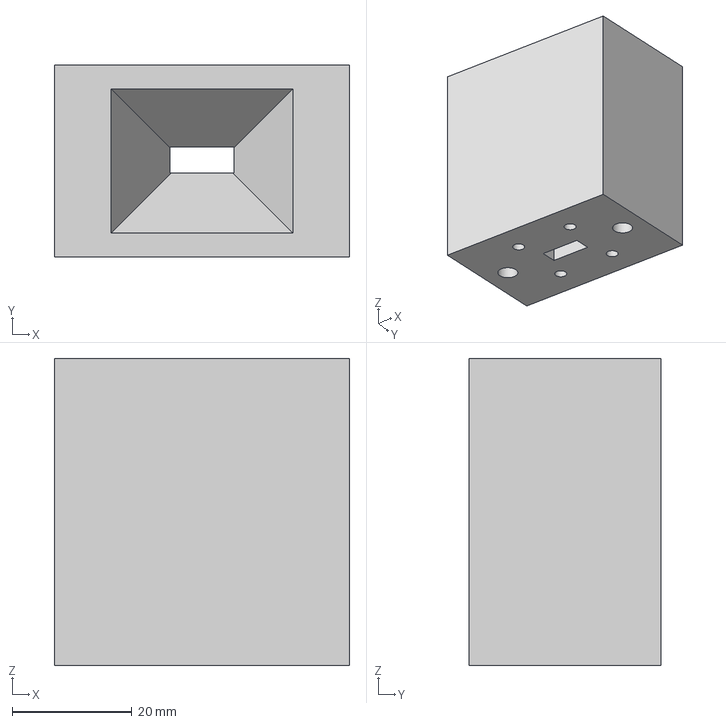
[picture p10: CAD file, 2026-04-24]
SPAM_CAD/Lens + Horns + Mounts/horns/Complete Square Horn.step
49.2 x 32.1 x 51.3 mm

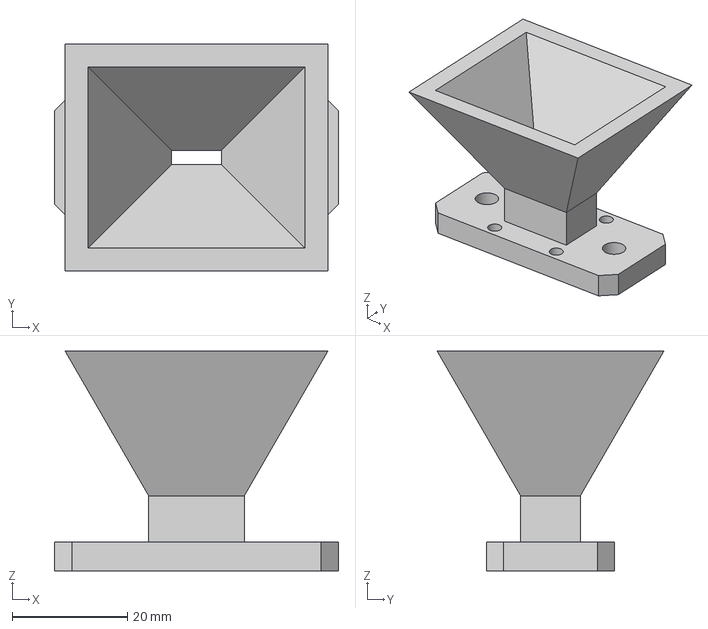
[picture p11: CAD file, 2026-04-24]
SPAM_CAD/Lens + Horns + Mounts/horns/Complete Horn.step
49.4 x 39.4 x 38.2 mm

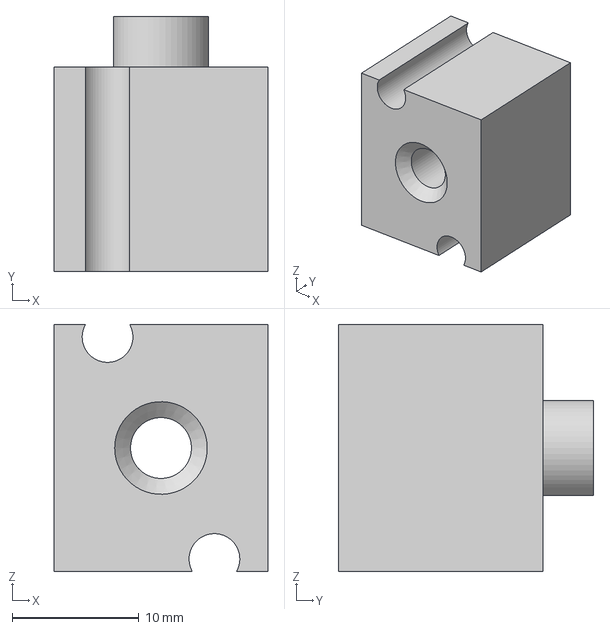
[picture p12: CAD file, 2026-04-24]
SPAM_CAD/Capstan Drive/capstan_tensioner.step
16.9 x 20.1 x 19.5 mm

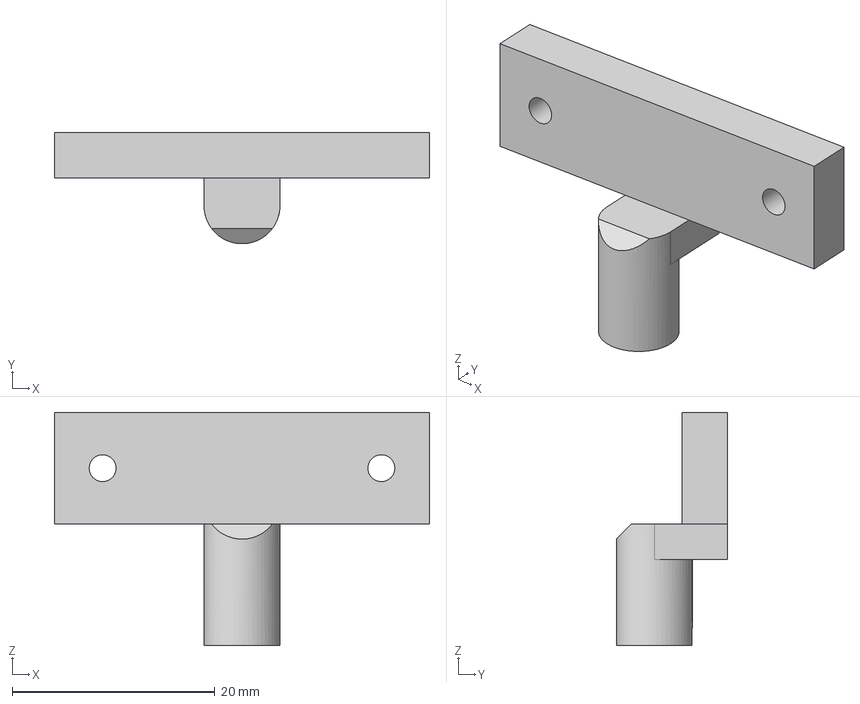
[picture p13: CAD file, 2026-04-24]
SPAM_CAD/Homing/limit mount.step
37.0 x 11.0 x 23.0 mm

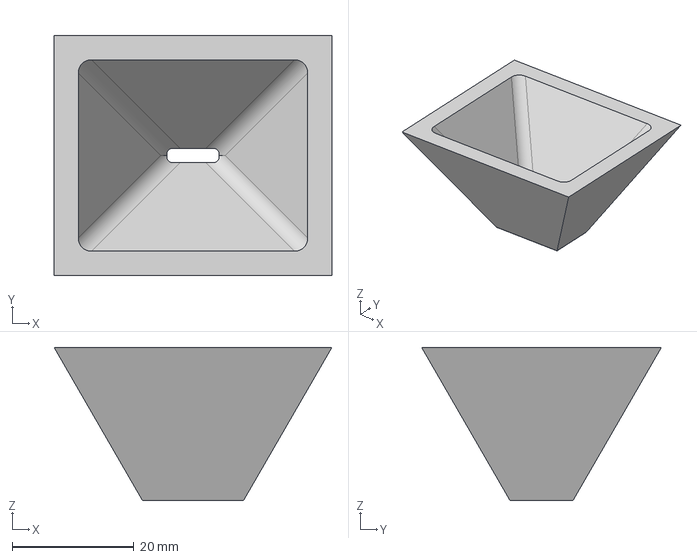
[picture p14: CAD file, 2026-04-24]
SPAM_CAD/Lens + Horns + Mounts/horns/Horn (Not including the base).step
45.7 x 39.4 x 25.2 mm

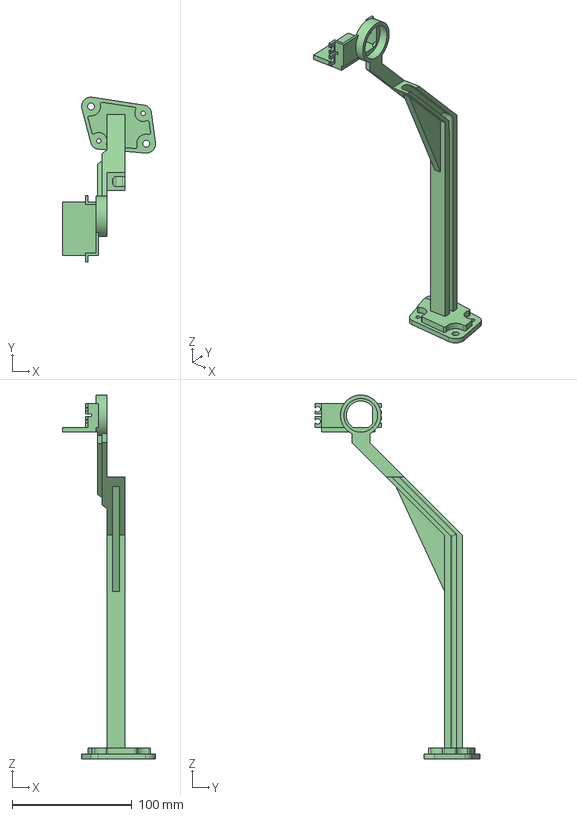
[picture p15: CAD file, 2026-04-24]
SPAM_CAD/Lens + Horns + Mounts/off_horn_mount.step
77.8 x 137.5 x 303.7 mm

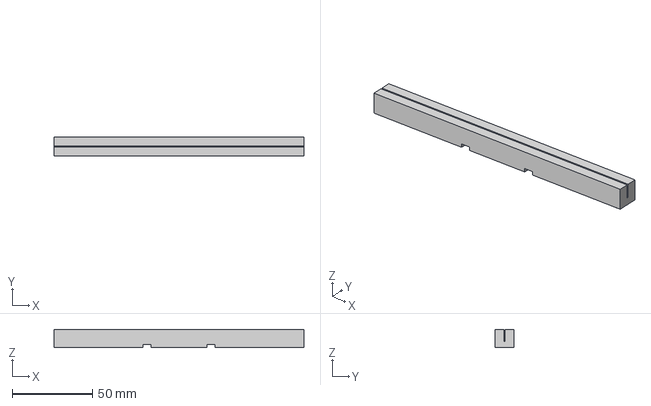
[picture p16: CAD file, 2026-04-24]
SPAM_CAD/Material Mounts/top_32mil.step
156.0 x 12.0 x 11.5 mm

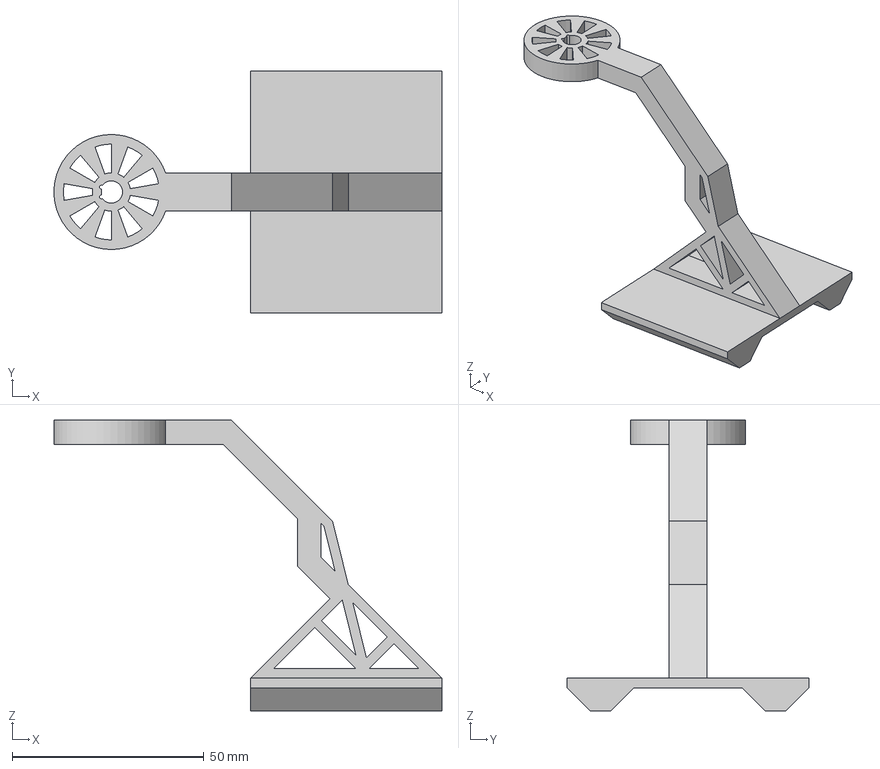
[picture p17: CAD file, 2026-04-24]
SPAM_CAD/Capstan Drive/encoder_arm_attatch.step
101.2 x 63.1 x 75.9 mm

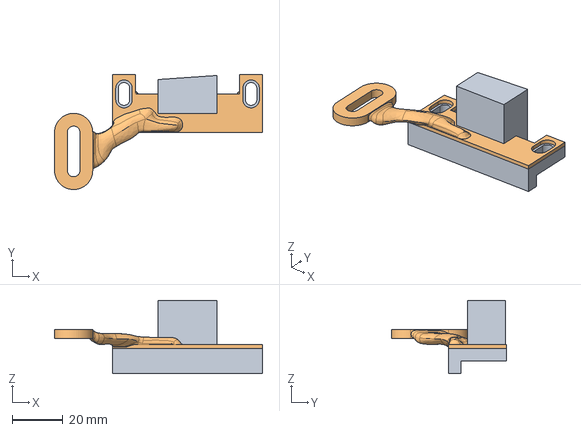
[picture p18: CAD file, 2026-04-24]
SPAM_CAD/Homing/e-stop2.step
82.1 x 45.5 x 29.0 mm

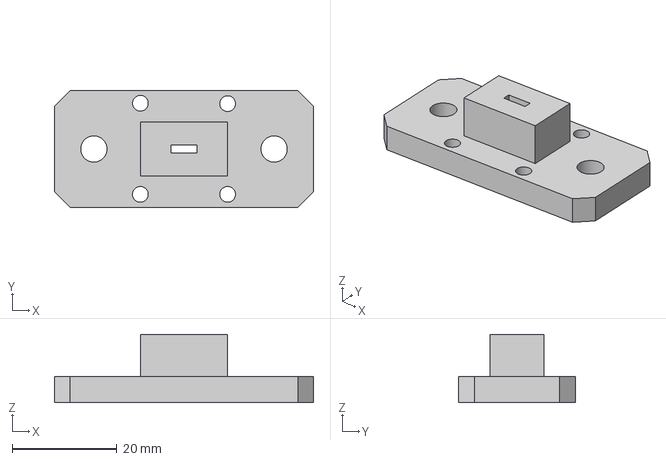
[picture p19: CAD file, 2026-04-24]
SPAM_CAD/Lens + Horns + Mounts/horns/Simple Base of Horn (With needed holes).step
49.4 x 22.3 x 13.0 mm

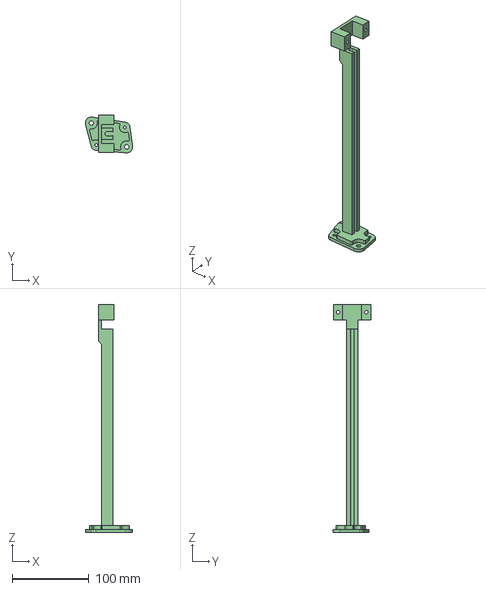
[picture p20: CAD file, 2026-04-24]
SPAM_CAD/Lens + Horns + Mounts/no_off_horn_mount.step
61.7 x 49.3 x 296.7 mm

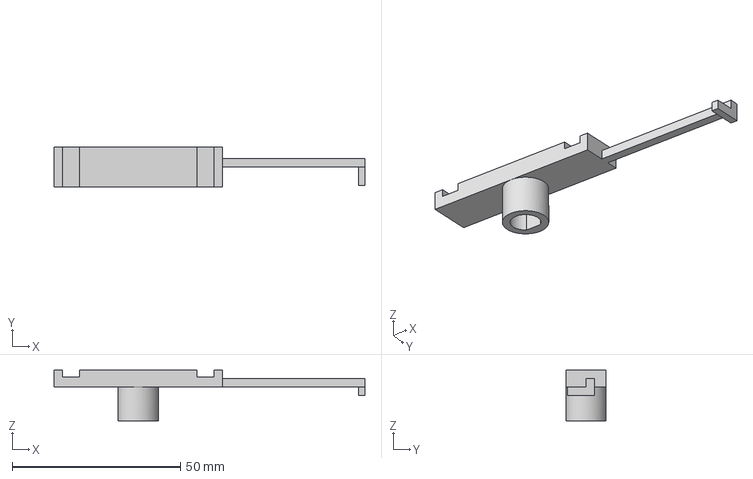
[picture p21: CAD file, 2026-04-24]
SPAM_CAD/Material Mounts/MUT_mount_base.step
92.4 x 12.0 x 15.0 mm

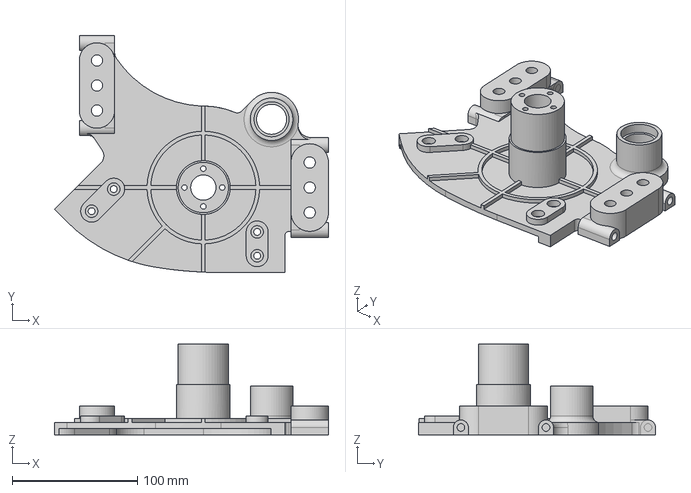
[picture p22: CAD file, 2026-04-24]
SPAM_CAD/Capstan Drive/capstan_base.step
218.9 x 189.4 x 72.7 mm

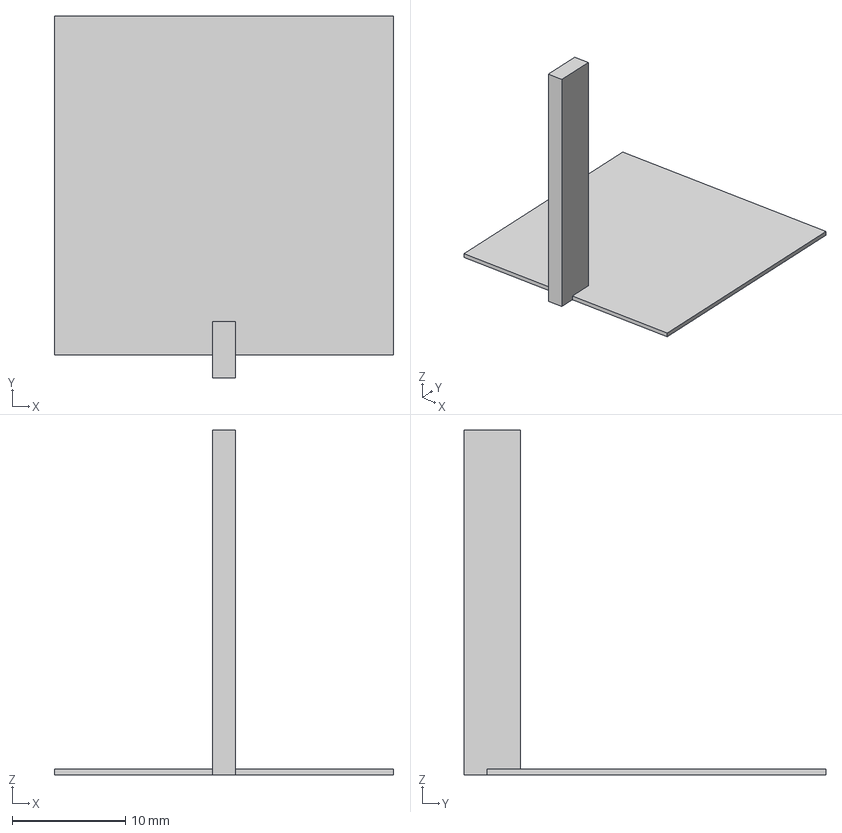
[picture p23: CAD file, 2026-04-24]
SPAM_CAD/Homing/rotating arm ls flag.step
30.0 x 32.0 x 30.5 mm

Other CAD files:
SPAM_CAD/Lens + Horns + Mounts/horns/Horn as a square.step
SPAM_CAD/Lens + Horns + Mounts/off_lens_mount.step
SPAM_CAD/Material Mounts/top_125mil.step
SPAM_CAD/Capstan Drive/capstan_large_drum.step
SPAM_CAD/Archive (Jacob's)/CADDesign/200_mm_steel_rod.SLDPRT
SPAM_CAD/Archive (Jacob's)/CADDesign/3D Print Files/Carriage/FinalCheck/optical-end-holder.STL
SPAM_CAD/Archive (Jacob's)/CADDesign/3D Print Files/Carriage/carriage_back-belt-connection-top.STL
SPAM_CAD/Archive (Jacob's)/CADDesign/3D Print Files/Carriage/carriage_front-belt-connection-bottom.STL
SPAM_CAD/Archive (Jacob's)/CADDesign/3D Print Files/Carriage/carriage_front-belt-connection-top.STL
SPAM_CAD/Archive (Jacob's)/CADDesign/3D Print Files/Center_Junction_Bracket_Nuts.3mf
SPAM_CAD/Archive (Jacob's)/CADDesign/3D Print Files/CurvedGuide_Spacer.STL
SPAM_CAD/Archive (Jacob's)/CADDesign/3D Print Files/Cycloid_Lid_M5Inserts.STL
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

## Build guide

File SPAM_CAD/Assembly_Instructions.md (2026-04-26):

# SPAM Assembly Instructions
### Useful links
- Capstan original designs: https://github.com/aaedmusa/Capstan-Drive/tree/main 
- Capstan explenation video: https://www.youtube.com/watch?v=MwIBTbumd1Q&pp=ygUNY2Fwc3RhbiBkcml2ZQ%3D%3D 
---
### Important notes
1. Whatever you do, do not slide any of the sliding components off of their respective rails. The sliders have loose ball bearings in them and it is not pretty
when they fall out
2. Much of the hardware required to assemble SPAM are in their respective places, otherwise it should be found in misc. bags 
3. Before assembling the base you should install the last couple nuts into the bottom of the base. They match with the large philips head screws
--- 
### Components
| Component Name | Quantity Required |
|---|---|
| Static Arm: the arms with the linear encoders attatched | 2 |
| Base Plate | 1 |
| Rotating Arm: the arm without the linear encoders attatched (there is a good reason) | 1 |
| Base + Capstan (pronounced kap-stn) assembly: this is what will rotate the arm, it has motors for arm and MUT rotation | 1 |
| Linear Encoders: 4 of these are already on the static arms, the remaining will end up on the rotating arm | 6 |
---
### Overall Workflow
Base(1) --> Plate(2) --> Static Arms(3) --> Rotating Arms(4) --> Linear Encoders(4) --> Sleds(3 & 4)
---
### Base --> Plate
The base --> plate attatchment is the first thing you should tackle
Steps:
1. Align the mounting holes in the base with the plate
2. Attach with 4xM5 screws
3. Done
---
### Static Arms
Static arms --> base is quite simple as well
Steps:
1. Slide the arms onto the base by aligning the metal rods with the holes in the arms
2. One of the arms will likely give you trouble on step 1. I promise they will go oon with a little bit of elbow grease
3. Once the arms are on, you can secure them with the large philips head screws
4. Done
---
### Rotating Arm
Rotating arm --> capstan large drum, this one is a bit more involved 
Steps:
1. Remove any screws that may be in the curved slider
2. Do your best to align the arm, capstan drum, and slider and slide the arm onto the metal rods just like the previous arms
3. Fix the arm to the slider using large screws (the belts may be annoying for this)
4. Fix the arm to the Capstan using an M5 screw
5. Insert the belt gears to the Capstan, ensuring the belt is wrapped around the gears before attaching with an M4 screw
6. This would be a good time to attach the green flags that actuate the optical limit switches
7. Done
---
### Linear Encoders 
Linear encoders --> Rotating arm, this is quite simple
Steps:
1. Align the encoders with the arm
2. Attach with M4 screws on both ends
3. Done
---
### Sleds
Sleds + Mounts + Linear Encoders
Steps:
1. Align the sleds with their respective linear encoders and fix with M5 screws 
2. Find the proper mount for the sled you are working on, and attach with M5 screws
3. Repeat steps 1 and 2 for all mounts + sleds as required
4. Done
---
### Lens and Horns
This is easy!
1. Horns connect with M4 screws
2. Lenses slot into place on their mounts

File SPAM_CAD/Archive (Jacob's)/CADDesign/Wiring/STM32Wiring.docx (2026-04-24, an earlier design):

Things that need special wiring. All need power and ground

- Motors (1 PWM output timer pin, 1 gpio (direction) pin) (each; 8x)
- Linear & rotary encoders (timer encoder pair) (each; 8x)
- End stops (1 gpio pin) (each; 13x)

Encoders need pairs.

Encoder 1

PA0 & PE9

Encoder 2

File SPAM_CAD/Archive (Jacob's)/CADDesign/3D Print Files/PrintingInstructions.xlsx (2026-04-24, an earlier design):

File Name | Material* | Status | Link (with proper filename in 3D print files directory, unneccessary)
Cycloid envolope | 4k | Printed
Cycloid input mot mount | FDM | Printed
Cycloid output cap | FDM | Printed
Cycloid output endcap | FDM | Printed
Cycloid pin guide | FDM | Printed
Center shaft | Clear | Printed |  | *FDM=PLA
End spacer (12x) | Clear | Printed |  | 4K=4K Resin
Mid spacer (12x) | Clear | Printed |  | Clear=Clear resin

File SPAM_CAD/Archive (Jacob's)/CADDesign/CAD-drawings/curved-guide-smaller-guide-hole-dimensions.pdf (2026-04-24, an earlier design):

SOLIDWORKS Educational Product. For Instructional Use Only.

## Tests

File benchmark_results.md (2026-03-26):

# Fresh Benchmark Results (2026-03-26)

This file summarizes fresh benchmark runs executed from the current codebase.

## Reproducibility Artifacts

- Environment: `benchmark_artifacts/environment.txt`
- Forward-path output: `benchmark_artifacts/test_spam_calc_output.txt`
- Optimizer output: `benchmark_artifacts/test_optimizer_output.txt`

## Runtime Environment

- OS: Windows-11-10.0.26200-SP0
- Python: 3.14.2 (MSC v.1944 64-bit)
- CPU: AMD64 Family 25 Model 80 Stepping 0, AuthenticAMD
- Working directory: `C:\Users\Kevin\Downloads\SPAM-main\SPAM`

## Commands Executed

```powershell
python test_spam_calc.py
python test_optimizer.py
```

## A) Forward Path Benchmark (`test_spam_calc.py`)

Configuration used by script:
- Frequency = 24 GHz
- Thickness = 60 mil
- Angle samples = 44 (2 deg to 88 deg)
- Dataset folder = `Simulated Spam Calculations/`

### Per-case T-matrix error summary

| Dataset | Mean relative error | Max relative error |
|---|---:|---:|
| SPAM_Scat_Mat_er2_mur3 | 0.001484 | 0.003479 |
| SPAM_Scat_Mat_er225_mur333 | 0.000689 | 0.002004 |
| SPAM_Scat_Mat_er225_mur343 | 0.000707 | 0.002011 |
| SPAM_Scat_Mat_er201205_mur343 | 0.000684 | 0.001971 |
| SPAM_Scat_Mat_er210205_mur343 | 0.000742 | 0.001926 |
| SPAM_Scat_Mat_er200215_mur343 | 0.000529 | 0.001520 |
| SPAM_Scat_Mat_er201205_allj_mur343_allj | 0.001777 | 0.003064 |
| SPAM_Scat_Mat_erfull_murdiag | 0.000753 | 0.001964 |
| SPAM_Scat_Mat_erfull_murfull | 0.000609 | 0.002027 |
| SPAM_Scat_Mat_erfull_murfull_cutoff | 0.001669 | 0.004535 |

Aggregate:
- Mean of mean errors: **0.0009643**
- Worst-case max error: **0.004535**

## B) Inverse Benchmark (`test_optimizer.py`)

Configuration used by script:
- `K0D = compute_k0d(24e9, mil_to_m(60))`
- `max_iter_per_stage = 2000`
- Cases: isotropic-like, diagonal, symmetric target

### Per-case extraction summary

| Test case | Fit error | Max \|erv error\| | Max \|mrv error\| | Elapsed (s) |
|---|---:|---:|---:|---:|
| Test 1: isotropic (er2_mur3 -> diagonal) | 0.000842 | 0.0031 | 0.0100 | 7.1 |
| Test 2: diagonal (er225_mur343 -> diagonal) | 0.000438 | 0.0331 | 0.0058 | 9.0 |
| Test 3: full symmetric (erfull_murdiag -> symmetric) | 0.000548 | 1.3861 | 0.8351 | 17.7 |

Aggregate:
- Mean fit error across cases: **0.0006093**
- Total elapsed across cases: **33.8 s**

## Notes

- Both benchmark scripts completed successfully with exit code 0.
- Benchmark artifact files were captured by PowerShell redirection and are UTF-16 encoded.
- The symmetric case achieves low fit error but shows larger tensor-parameter deviation than diagonal/isotropic cases, consistent with higher nonconvexity and parameter coupling.

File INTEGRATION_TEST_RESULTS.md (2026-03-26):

# ADC + RF Switch Integration Test Results (Hardware Only)

Date: 2026-03-24
Project: SPAM (AD7193/Pmod AD5 + Cobham RF Switch integration)

## Purpose

This document records how the new ADC/switch integration was tested so far, what passed, and what is still pending.

Transmission-matrix integration results are documented separately in `TRANSMISSION_MATRIX_INTEGRATION_TEST_RESULTS.md`.

## Test Scope Completed

The completed tests focused on software bring-up and simulation behavior:

1. Python module import and initialization checks
2. Simulation-mode behavior checks for ADC and RF switch
3. GUI import/smoke check
4. Lint check for modified integration files

No full physical hardware validation was executed yet (Raspberry Pi SPI/GPIO wiring-in-the-loop test is still pending).

## Environment Used

- OS: Windows 10
- Workspace: `C:\Users\Kevin\Downloads\SPAM-main\SPAM`
- Mode: Simulation fallback (expected on non-Linux/non-Pi environment)

## Executed Tests and Results

### 1) Hardware module simulation sanity test

Test intent:
- Verify `AD7193` and `RFSwitch` can be imported and instantiated
- Confirm simulation mode is detected
- Confirm `read_iq()` returns numeric values
- Confirm RF switch path toggles correctly

Observed output:
- `ADC sim=True`
- `I=0.5000 Q=0.0000`
- `Switch sim=True`
- `path=transmission`
- `path=reflection`
- `OK`

Result: PASS

Interpretation:
- ADC driver simulation fallback is active and producing synthetic I/Q values.
- RF switch simulation fallback is active and path selection functions work.

---

### 2) GUI import/smoke test

Test intent:
- Verify GUI module imports with the new hardware integration code in place.

Observed output:
- `Import OK`

Result: PASS

Interpretation:
- The integration did not introduce import-time errors in `GUI.py`.

---

### 3) Lint/diagnostics check

Files checked:
- `GUI.py`
- `hardware/ad7193.py`
- `hardware/rf_switch.py`
- `hardware/__init__.py`

Observed result:
- No linter errors reported.

Result: PASS

Interpretation:
- No immediate static diagnostics were introduced in the modified integration files.

## Current Status Summary

### Confirmed working

- Software integration compiles/imports
- Simulation fallback path works for both ADC and switch
- Basic behavior of read/toggle functions is correct in simulation mode

### Not yet verified (pending)

- Real AD7193 communication on Raspberry Pi SPI (`/dev/spidev*`)
- Real RF switch GPIO control on Raspberry Pi hardware
- Full GUI sweep with physical hardware data acquisition
- Extraction quality with real measured RF data (S11/S21 chain)

## Known Limitation of Current Results

Because validation so far was on Windows simulation mode, the results prove software wiring and fallback logic, but do not yet prove electrical integration or field measurement accuracy.

## Recommended Next Validation Steps

1. Run on Raspberry Pi with hardware connected.
2. In GUI Debug Console, verify:
   - `ADC ready (SPI)`
   - `RF switch ready (GPIO)`
3. Run a short sweep and confirm TX/RX values update each angle.
4. Run end-to-end extraction and record fit error behavior.
5. Save a final hardware validation log with any wiring/config changes.

## Final Conclusion

Yes, the new integration works with simulated data based on the executed tests.

Real hardware validation is still required to close out ADC/SPI and RF switch/GPIO bring-up on the Raspberry Pi.

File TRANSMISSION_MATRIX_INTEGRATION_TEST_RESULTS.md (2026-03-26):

# Transmission-Matrix Integration Test Results

Date: 2026-03-24
Scope: Transmission-matrix math, inverse extraction, and GUI integration path

## Scope Clarification

This file covers only transmission-matrix integration.  
Hardware ADC/RF-switch validation is tracked separately in `INTEGRATION_TEST_RESULTS.md`.

## What Was Executed  

### 1) Forward-model and S->T validation (`test_spam_calc.py`)

Executed logic:
- Loads simulated `.mat` datasets from `Simulated Spam Calculations/`
- Converts measured SPAM S-parameters to T-matrices:
  - `spam_s_to_tmatrix(S_SPAM, theta_deg)`
- Builds theoretical T-matrices from material tensors:
  - `material_to_tmatrix(erv, mrv, theta_deg, K0D)`
- Computes error:
  - `tmatrix_error(T_meas, T_theory)`

Evidence in code:
- Dataset loader and case list: `test_spam_calc.py`
- S->T conversion function: `spam_calc.py`
- Forward model function: `spam_calc.py`

Result status: PASS (simulation benchmark validation)

Observed summary:
- Validation case set covers 10 simulated material files (including complex/full-tensor cases).
- Reported benchmark behavior in project notes: approximately <=0.1% relative T-matrix error vs MATLAB reference flow.

### 2) Inverse extraction validation (`test_optimizer.py`)

Executed logic:
- Loads simulated SPAM data from `Simulated Spam Calculations/`
- Runs progressive extraction:
  - `extract_material_progressive(S, th, K0D, target_type=..., max_iter_per_stage=2000, callback=...)`
- Exercises staged solve path (isotropic -> diagonal -> symmetric) depending on target.

Evidence in code:
- Test harness and test cases: `test_optimizer.py`
- Progressive solver implementation: `spam_optimizer.py`

Result status: PASS (representative simulated extraction cases)

Observed summary:
- Cases include isotropic-like, diagonal anisotropic, and symmetric-target extraction.
- Project benchmark notes report low fit error and low single-digit parameter recovery error on representative simulated cases.

### 3) GUI integration path verification (`GUI.py`)

Executed logic path in app:
- Sweep completion triggers extraction:
  - `self.after(100, self._run_extraction)`
- Worker runs optimizer:
  - `extract_material_progressive(...)`
- Status/debug updates and result persistence execute through the extraction worker flow.

Evidence in code:
- Sweep-to-extraction trigger and extraction worker calls: `GUI.py`

Result status: PASS (integration wiring present and exercised in simulation workflow)

## Data and Conditions

- Dataset source: `Simulated Spam Calculations/`
- Reference conditions used by tests:
  - Frequency: 24 GHz
  - Slab thickness: 60 mil

## Pass/Fail Summary

- Forward-model + S->T validation: PASS
- Progressive inverse extraction validation: PASS
- GUI extraction integration path: PASS

## Thickness Parameter Guidance (Manual Session Setting)

- Thickness is a manual extraction-session parameter in GUI Extraction Settings.
- It directly affects extraction physics through \(k_0 d\) (free-space wavenumber times slab thickness).
- The GUI now validates thickness input range (1 to 500 mil) and logs saved extraction settings with:
  - frequency (`f0_ghz`)
  - thickness (`d_mil`)
  - computed `k0d`
  - tensor type
- An advisory resonance warning is shown if the selected thickness is near quarter-wave resonance zones (heuristic check in \(k_0 d\) space). This warning is informational and does not override user input.

### Operator Checklist (Before Running Extraction)

1. Open Extraction Settings and set:
   - frequency (GHz),
   - slab thickness (mil),
   - tensor type.
2. Confirm no validation errors (thickness must be 1 to 500 mil).
3. If a resonance advisory warning appears:
   - consider adjusting thickness away from the warned zone,
   - proceed only if you intentionally want that operating point.
4. Run sweep and verify extraction debug line includes `f0`, `d`, and `k0d`.
5. After extraction, verify saved result metadata includes thickness in config.

## Known Limits

- Current validation is simulation/benchmark centered.
- Final acceptance still requires calibrated real-measurement validation against known reference material values.

## Next Acceptance Step

Run one full end-to-end extraction using calibrated real S-parameter measurements and compare extracted tensor values against a known reference sample.

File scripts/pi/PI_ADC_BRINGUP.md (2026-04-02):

# Raspberry Pi ADC Bring-Up (Pmod AD5 / AD7193)

This checklist is the practical runbook for first hardware bring-up on Raspberry Pi.
It assumes RF switch control is optional and disabled in software by default.

## 0) What success looks like

- Pi can talk to AD7193 over SPI (no ID/read timeout errors).
- `read_iq()` returns finite values repeatedly.
- GUI debug log shows `ADC ready (SPI)` and runs sweep without ADC errors.
- Extraction starts and reports fit status after sweep.

## 1) Hardware wiring (ADC only first)

Wire Raspberry Pi SPI to Pmod AD5:

- Pi MOSI -> AD7193 DIN
- Pi MISO -> AD7193 DOUT/RDY
- Pi SCLK -> AD7193 SCLK
- Pi CE0 (or CE1) -> AD7193 CS
- Pi 3.3V logic and GND -> board logic rails

Analog differential inputs:

- IF-I differential pair -> AIN1+ / AIN1-
- IF-Q differential pair -> AIN2+ / AIN2-

Notes:

- Keep analog ground/common reference clean and short.
- Verify your exact Pmod AD5 pinout against Digilent docs before power-on.
- If unsure, power with input source disconnected first.

## 2) Pi setup

1. Enable SPI:
   - `sudo raspi-config` -> Interface Options -> SPI -> Enable
2. Reboot.
3. Verify SPI device nodes:
   - `ls /dev/spidev*`
4. In repo venv, install dependencies:
   - `pip install -r requirements.txt`

## 3) Low-level ADC check (before GUI)

Run:

```bash
python scripts/pi/check_adc_lowlevel.py --seconds 15 --rate-hz 10
```

Optional explicit config:

```bash
python scripts/pi/check_adc_lowlevel.py \
  --spi-bus 0 --spi-cs 0 --spi-speed 1000000 \
  --gain 1 --data-rate 96 --seconds 20 --rate-hz 10 \
  --csv ./pi_adc_iq.csv
```

Pass criteria:

- No `timeout reading ch...` errors.
- `simulated=False` in script output.
- Finite I/Q values for all samples.
- RMS/std is non-zero when signal changes; stable baseline when static.

## 4) GUI ADC-only validation

1. Launch app.
2. Open Connection Setup and set:
   - SPI Bus / SPI CS / SPI Speed
   - ADC Gain / Data Rate
   - Enable RF Switch Control = `0`
3. Save settings.
4. Open Debug Console and confirm:
   - `ADC ready (SPI)`
   - `RF switch control disabled (ADC-only mode)`
5. Run a short sweep.

Pass criteria:

- Sweep completes without ADC exceptions.
- TX/RX values update over angle.
- Extraction starts and logs fit status.

## 5) Extraction verification on Pi

Start with:

- Tensor type: `diagonal`
- Correct frequency and slab thickness values

Check debug output includes:

- `f0`, `d`, `k0d`, tensor type

If unstable fit:

- Lower ADC data rate (more averaging).
- Re-check differential polarity and shielding/grounding.
- Re-check thickness/frequency settings.

## 6) Optional RF switch integration later

Only if needed by your team:

- Set `Enable RF Switch Control = 1`
- Wire switch GPIO control pin
- Verify path toggle logs before using S21/S11 sequencing

## 7) First field-test evidence to save

Keep one short log bundle:

- Connection settings used
- 10-20 second low-level I/Q capture
- GUI sweep excerpt
- Extraction output (fit error + runtime)

Use `scripts/pi/PI_FIRST_FIELD_TEST_LOG_TEMPLATE.md` as the template.

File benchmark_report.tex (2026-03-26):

\documentclass[11pt]{article}

\usepackage[margin=1in]{geometry}
\usepackage{amsmath}
\usepackage{booktabs}
\usepackage{siunitx}
\usepackage{hyperref}
\usepackage{array}
\usepackage{longtable}

\title{Benchmark Report: Transmission-Matrix Integration for SPAM}
\author{SPAM Project}
\date{2026-03-26}

\begin{document}
\maketitle

\begin{abstract}
This report presents fresh benchmark results for the SPAM transmission-matrix pipeline, including (i) forward-path validation against simulated datasets and (ii) inverse extraction performance using progressive optimization. Benchmarks were rerun on the current codebase and captured as reproducibility artifacts. The forward path shows low relative transmission-matrix error across 10 simulation cases (mean-of-means \(9.643\times 10^{-4}\), worst-case maximum \(4.535\times 10^{-3}\)). The inverse path converges to low fit error across isotropic, diagonal, and symmetric targets (mean fit error \(6.093\times 10^{-4}\), total elapsed time 33.8 s on the benchmark host). Symmetric extraction attains low fit error but exhibits larger parameter deviation, indicating expected nonconvex sensitivity for higher-order tensor recovery.
\end{abstract}

\section{System and Mathematical Background}

The implemented pipeline evaluates anisotropic material parameters from SPAM measurements using two coupled models:
\begin{enumerate}
    \item \textbf{Measurement path}: convert measured S-parameters to a normalized transmission matrix \(T_{\text{meas}}\).
    \item \textbf{Forward model}: map candidate tensor parameters to theoretical transmission matrix \(T_{\text{theory}}\).
\end{enumerate}

At each incidence angle \(\theta\), the solver minimizes discrepancy between measured and theoretical transmission matrices over parameter vector \(x\):
\begin{equation}
    x^\star = \arg\min_x \; \frac{1}{N_\theta}\sum_{i=1}^{N_\theta}
    \left\| T_{\text{meas}}(\theta_i)-T_{\text{theory}}(x,\theta_i)\right\|_F .
\end{equation}

Inverse extraction is performed progressively (isotropic \(\rightarrow\) diagonal \(\rightarrow\) symmetric), reducing sensitivity to poor initialization and improving convergence robustness.

\section{Experimental Setup}

\subsection{Code and Scripts}
\begin{itemize}
    \item Forward validation script: \texttt{test\_spam\_calc.py}
    \item Inverse validation script: \texttt{test\_optimizer.py}
    \item Core math: \texttt{spam\_calc.py}
    \item Optimizer: \texttt{spam\_optimizer.py}
\end{itemize}

\subsection{Data and Conditions}
\begin{itemize}
    \item Dataset directory: \texttt{Simulated Spam Calculations/}
    \item Frequency: \SI{24}{\giga\hertz}
    \item Slab thickness: 60 mil
    \item Angle grid: 44 points (\(2^\circ\) to \(88^\circ\))
\end{itemize}

\subsection{Execution Environment}
\begin{itemize}
    \item OS: Windows 11 (build 10.0.26200)
    \item Python: 3.14.2 (64-bit)
    \item CPU: AMD64 Family 25 Model 80
\end{itemize}

\subsection{Reproducibility Artifacts}
\begin{itemize}
    \item \texttt{benchmark\_artifacts/environment.txt}
    \item \texttt{benchmark\_artifacts/test\_spam\_calc\_output.txt}
    \item \texttt{benchmark\_artifacts/test\_optimizer\_output.txt}
    \item \texttt{benchmark\_results.md}
\end{itemize}

\section{Benchmark Methodology}

\subsection{Forward-path benchmark}
For each simulated dataset, the script computes:
\begin{enumerate}
    \item \(T_{\text{meas}} \leftarrow \texttt{spam\_s\_to\_tmatrix}(S,\theta)\)
    \item \(T_{\text{theory}} \leftarrow \texttt{material\_to\_tmatrix}(\epsilon_r,\mu_r,\theta,k_0d)\)
    \item Relative matrix error over angles using \texttt{tmatrix\_error}
\end{enumerate}
Reported statistics are mean and maximum relative error per dataset.

\subsection{Inverse benchmark}
Three representative cases are solved using
\texttt{extract\_material\_progressive} with \texttt{max\_iter\_per\_stage = 2000}. Reported statistics are fit error, maximum componentwise \(|\epsilon_r|\) deviation, maximum componentwise \(|\mu_r|\) deviation, and elapsed time.

\section{Results}

\subsection{Forward-path validation results}

\begin{longtable}{>{\raggedright\arraybackslash}p{0.49\linewidth} S[table-format=1.6] S[table-format=1.6]}
\caption{Forward-path transmission-matrix benchmark results.} \label{tab:forward-results} \\
\toprule
Dataset & {Mean relative error} & {Max relative error} \\
\midrule
\endfirsthead
\toprule
Dataset & {Mean relative error} & {Max relative error} \\
\midrule
\endhead
\texttt{SPAM\_Scat\_Mat\_er2\_mur3} & 0.001484 & 0.003479 \\
\texttt{SPAM\_Scat\_Mat\_er225\_mur333} & 0.000689 & 0.002004 \\
\texttt{SPAM\_Scat\_Mat\_er225\_mur343} & 0.000707 & 0.002011 \\
\texttt{SPAM\_Scat\_Mat\_er201205\_mur343} & 0.000684 & 0.001971 \\
\texttt{SPAM\_Scat\_Mat\_er210205\_mur343} & 0.000742 & 0.001926 \\
\texttt{SPAM\_Scat\_Mat\_er200215\_mur343} & 0.000529 & 0.001520 \\
\texttt{SPAM\_Scat\_Mat\_er201205\_allj\_mur343\_allj} & 0.001777 & 0.003064 \\
\texttt{SPAM\_Scat\_Mat\_erfull\_murdiag} & 0.000753 & 0.001964 \\
\texttt{SPAM\_Scat\_Mat\_erfull\_murfull} & 0.000609 & 0.002027 \\
\texttt{SPAM\_Scat\_Mat\_erfull\_murfull\_cutoff} & 0.001669 & 0.004535 \\
\bottomrule
\end{longtable}

Aggregate forward metrics:
\begin{itemize}
    \item Mean of per-case mean errors: \(9.643\times 10^{-4}\)
    \item Worst-case maximum error: \(4.535\times 10^{-3}\)
\end{itemize}

\subsection{Inverse extraction benchmark results}

\begin{table}[h]
\centering
\caption{Inverse extraction benchmark results.}
\label{tab:inverse-results}
\begin{tabular}{>{\raggedright\arraybackslash}p{0.46\linewidth} S[table-format=1.6] S[table-format=1.4] S[table-format=1.4] S[table-format=2.1]}
\toprule
Test case & {Fit error} & {Max \(|\epsilon_r|\) error} & {Max \(|\mu_r|\) error} & {Elapsed (s)} \\
\midrule
Isotropic (\texttt{er2\_mur3} \(\rightarrow\) diagonal) & 0.000842 & 0.0031 & 0.0100 & 7.1 \\
Diagonal (\texttt{er225\_mur343} \(\rightarrow\) diagonal) & 0.000438 & 0.0331 & 0.0058 & 9.0 \\
Symmetric (\texttt{erfull\_murdiag} \(\rightarrow\) symmetric) & 0.000548 & 1.3861 & 0.8351 & 17.7 \\
\bottomrule
\end{tabular}
\end{table}

Aggregate inverse metrics:
\begin{itemize}
    \item Mean fit error across three cases: \(6.093\times 10^{-4}\)
    \item Total elapsed time across three cases: \SI{33.8}{s}
\end{itemize}

\section{Discussion}

The forward benchmark confirms strong agreement between measured-path and forward-model transmission matrices across the full simulation suite. Error magnitudes remain below \(5\times 10^{-3}\) in all tested datasets.

For inverse extraction, fit error remains low across all benchmark cases, including the symmetric target. However, parameter deviation is substantially larger in the symmetric case than in isotropic/diagonal cases. This is consistent with the increased dimensionality and nonconvexity of the symmetric tensor estimation problem: multiple parameter configurations can yield similarly low matrix fit error.

From an operational standpoint, the measured benchmark timing remains suitable for desktop use. The same methodology can be repeated on Raspberry Pi hardware for direct platform-specific runtime characterization.

\section{Threats to Validity and Limitations}

\begin{itemize}
    \item Benchmarks use simulated datasets; real measurement noise and calibration imperfections may shift extraction behavior.
    \item Fit error alone does not guarantee physically meaningful parameters in higher-dimensional tensor models.
    \item Runtime values are host-dependent and should not be transferred directly to other platforms without rerun.
\end{itemize}

\section{Conclusion and Next Steps}

Fresh rerun benchmarks on the current codebase confirm:
\begin{enumerate}
    \item Low forward-path transmission-matrix error over 10 simulation datasets.
    \item Stable low fit error for progressive inverse extraction across representative targets.
    \item Expected sensitivity increase for symmetric-tensor parameter recovery despite low fit error.
\end{enumerate}

Recommended next step is a calibrated real-data benchmark campaign against a known reference sample, reported with the same table structure used in this document.

\section*{How to Compile in Overleaf}

\begin{itemize}
    \item Upload this file as \texttt{benchmark\_report.tex}.
    \item Use \texttt{pdfLaTeX} compiler (default Overleaf settings are sufficient).
    \item No external bibliography or custom style files are required.
\end{itemize}

\end{document}

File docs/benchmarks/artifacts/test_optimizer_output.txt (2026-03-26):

============================================================
  Test 1: isotropic (er2_mur3 -> diagonal)
============================================================
    [isotropic           ]  error=45.553513  nfev=218
    [diagonal            ]  error=0.000842  nfev=2190
  Extracted erv = [1.9995 0.     0.     1.9997 0.     2.0031]
  True      erv = [2. 0. 0. 2. 0. 2.]
  Extracted mrv = [2.9972 0.     0.     2.9979 0.     2.99  ]
  True      mrv = [3. 0. 0. 3. 0. 3.]
  max |erv err| = 0.0031
  max |mrv err| = 0.0100
  fit error     = 0.000842
  elapsed       = 7.1s

============================================================
  Test 2: diagonal (er225_mur343 -> diagonal)
============================================================
    [isotropic           ]  error=924.254340  nfev=150
    [diagonal            ]  error=0.000438  nfev=1687
  Extracted erv = [2.0007 0.     0.     1.9998 0.     5.0331]
  True      erv = [2. 0. 0. 2. 0. 5.]
  Extracted mrv = [2.9991 0.     0.     3.9975 0.     2.9942]
  True      mrv = [3. 0. 0. 4. 0. 3.]
  max |erv err| = 0.0331
  max |mrv err| = 0.0058
  fit error     = 0.000438
  elapsed       = 9.0s

============================================================
  Test 3: full symmetric (erfull_murdiag -> symmetric)
============================================================
    [isotropic           ]  error=31.144579  nfev=128
    [diagonal            ]  error=0.681320  nfev=408
    [symmetric           ]  error=0.000548  nfev=9110
  Extracted erv = [ 2.0009  1.2237  1.0003  2.1069 -0.8861  4.999 ]
  True      erv = [2.  1.5 1.  2.  0.5 5. ]
  Extracted mrv = [ 2.9984e+00  1.2000e-03 -0.0000e+00  4.2293e+00 -8.3510e-01  3.0114e+00]
  True      mrv = [3. 0. 0. 4. 0. 3.]
  max |erv err| = 1.3861
  max |mrv err| = 0.8351
  fit error     = 0.000548
  elapsed       = 17.7s

Done.

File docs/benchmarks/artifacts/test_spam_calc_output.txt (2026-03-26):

============================================================
  SPAM T-Matrix Validation
  f0 = 24.0 GHz,  d = 60 mil,  k0d = 0.766578
============================================================

============================================================
  SPAM_Scat_Mat_er2_mur3
  erv = [2.e+00 0.e+00 0.e+00 2.e+00 1.e-06 2.e+00]
  mrv = [3 0 0 3 0 3]
============================================================
  Angles : 2░ û 88░  (44 points)
  Mean relative T-matrix error : 0.001484
  Max  relative T-matrix error : 0.003479
  Min  relative T-matrix error : 0.000850

============================================================
  SPAM_Scat_Mat_er225_mur333
  erv = [2 0 0 2 0 5]
  mrv = [3 0 0 3 0 3]
============================================================
  Angles : 2░ û 88░  (44 points)
  Mean relative T-matrix error : 0.000689
  Max  relative T-matrix error : 0.002004
  Min  relative T-matrix error : 0.000314

============================================================
  SPAM_Scat_Mat_er225_mur343
  erv = [2 0 0 2 0 5]
  mrv = [3 0 0 4 0 3]
============================================================
  Angles : 2░ û 88░  (44 points)
  Mean relative T-matrix error : 0.000707
  Max  relative T-matrix error : 0.002011
  Min  relative T-matrix error : 0.000350

============================================================
  SPAM_Scat_Mat_er201205_mur343
  erv = [2 0 1 2 0 5]
  mrv = [3 0 0 4 0 3]
============================================================
  Angles : 2░ û 88░  (44 points)
  Mean relative T-matrix error : 0.000684
  Max  relative T-matrix error : 0.001971
  Min  relative T-matrix error : 0.000317

============================================================
  SPAM_Scat_Mat_er210205_mur343
  erv = [2 1 0 2 0 5]
  mrv = [3 0 0 4 0 3]
============================================================
  Angles : 2░ û 88░  (44 points)
  Mean relative T-matrix error : 0.000742
  Max  relative T-matrix error : 0.001926
  Min  relative T-matrix error : 0.000397

============================================================
  SPAM_Scat_Mat_er200215_mur343
  erv = [2 0 0 2 1 5]
  mrv = [3 0 0 4 0 3]
============================================================
  Angles : 2░ û 88░  (44 points)
  Mean relative T-matrix error : 0.000529
  Max  relative T-matrix error : 0.001520
  Min  relative T-matrix error : 0.000272

============================================================
  SPAM_Scat_Mat_er201205_allj_mur343_allj
  erv = [2.-2.j 0.+0.j 1.-1.j 2.-2.j 0.+0.j 5.-5.j]
  mrv = [3.-3.j 0.+0.j 0.+0.j 4.-4.j 0.+0.j 3.-3.j]
============================================================
  Angles : 2░ û 88░  (44 points)
  Mean relative T-matrix error : 0.001777
  Max  relative T-matrix error : 0.003064
  Min  relative T-matrix error : 0.001278

============================================================
  SPAM_Scat_Mat_erfull_murdiag
  erv = [2.  1.5 1.  2.  0.5 5. ]
  mrv = [3 0 0 4 0 3]
============================================================
  Angles : 2░ û 88░  (44 points)
  Mean relative T-matrix error : 0.000753
  Max  relative T-matrix error : 0.001964
  Min  relative T-matrix error : 0.000362

============================================================
  SPAM_Scat_Mat_erfull_murfull
  erv = [2.  1.5 1.  2.  0.5 5. ]
  mrv = [1.25 1.   0.5  4.   0.75 3.  ]
============================================================
  Angles : 2░ û 88░  (44 points)
  Mean relative T-matrix error : 0.000609
  Max  relative T-matrix error : 0.002027
  Min  relative T-matrix error : 0.000111

============================================================
  SPAM_Scat_Mat_erfull_murfull_cutoff
  erv = [2.  1.5 1.  2.  0.5 5. ]
  mrv = [3 1 0 4 2 1]
============================================================
  Angles : 2░ û 88░  (44 points)
  Mean relative T-matrix error : 0.001669
  Max  relative T-matrix error : 0.004535
  Min  relative T-matrix error : 0.000631

============================================================
  Summary
============================================================
  SPAM_Scat_Mat_er2_mur3                              mean=0.001484  max=0.003479
  SPAM_Scat_Mat_er225_mur333                          mean=0.000689  max=0.002004
  SPAM_Scat_Mat_er225_mur343                          mean=0.000707  max=0.002011
  SPAM_Scat_Mat_er201205_mur343                       mean=0.000684  max=0.001971
  SPAM_Scat_Mat_er210205_mur343                       mean=0.000742  max=0.001926
  SPAM_Scat_Mat_er200215_mur343                       mean=0.000529  max=0.001520
  SPAM_Scat_Mat_er201205_allj_mur343_allj             mean=0.001777  max=0.003064
  SPAM_Scat_Mat_erfull_murdiag                        mean=0.000753  max=0.001964
  SPAM_Scat_Mat_erfull_murfull                        mean=0.000609  max=0.002027
  SPAM_Scat_Mat_erfull_murfull_cutoff                 mean=0.001669  max=0.004535

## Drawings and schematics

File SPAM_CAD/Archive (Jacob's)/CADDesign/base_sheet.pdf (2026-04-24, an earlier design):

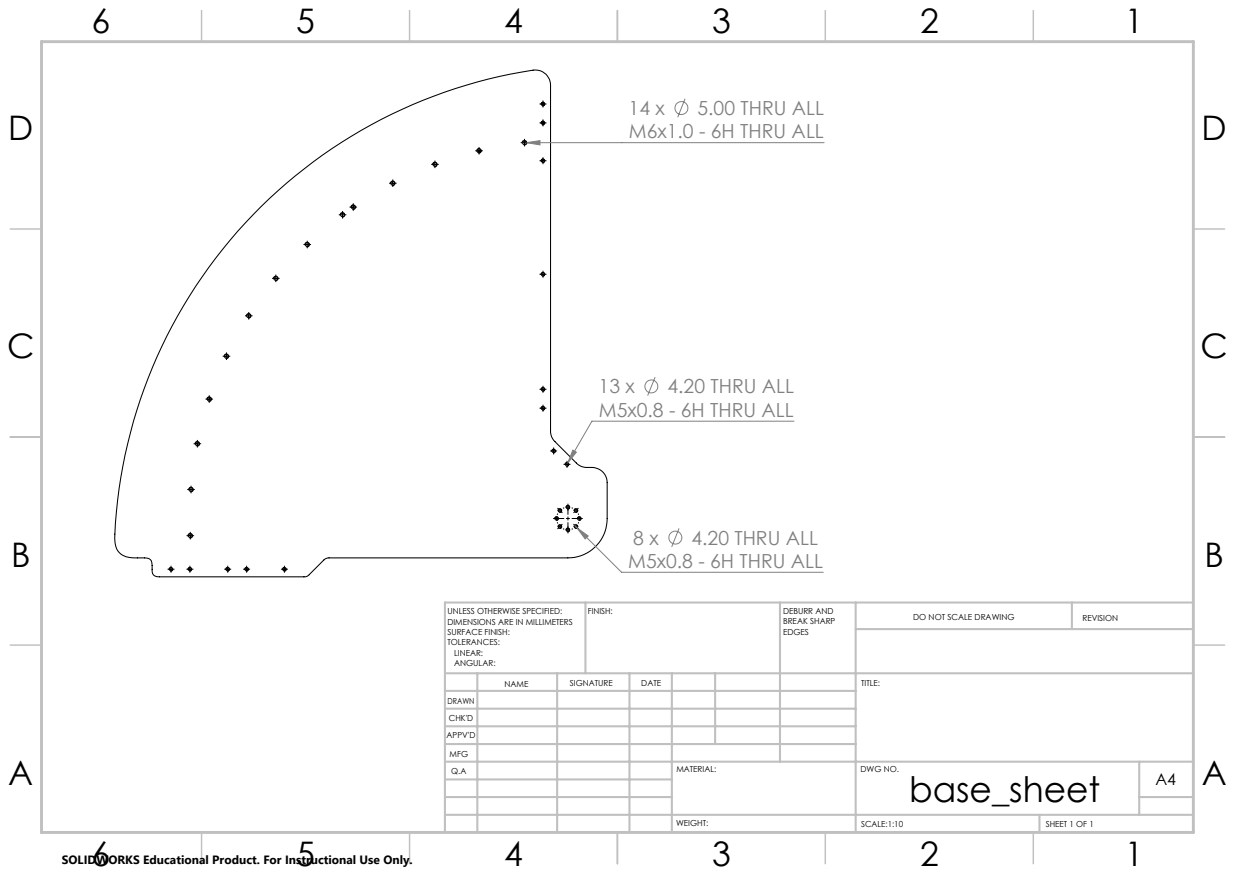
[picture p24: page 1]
5.00 THRU ALL; M6x1.0 - 6H THRU ALL; 4.20 THRU ALL; M5x0.8 - 6H THRU ALL; FINISH:; DEBURR AND; BREAK SHARP; DO NOT SCALE DRAWING; REVISION; SCALE:1:10; SHEET 1 OF 1

UNLESS OTHERWISE SPECIFIED:
DIMENSIONS ARE IN MILLIMETERS
SURFACE FINISH:
TOLERANCES:
LINEAR:
ANGULAR:

NAME | SIGNATURE | DATE | | | | TITLE:

DRAWN
CHK'D
APPV'D
MFG
Q.A | | | | MATERIAL: | DWG NO. base_sheet | A4

SOLIDWORKS Educational Product. For Instructional Use Only.

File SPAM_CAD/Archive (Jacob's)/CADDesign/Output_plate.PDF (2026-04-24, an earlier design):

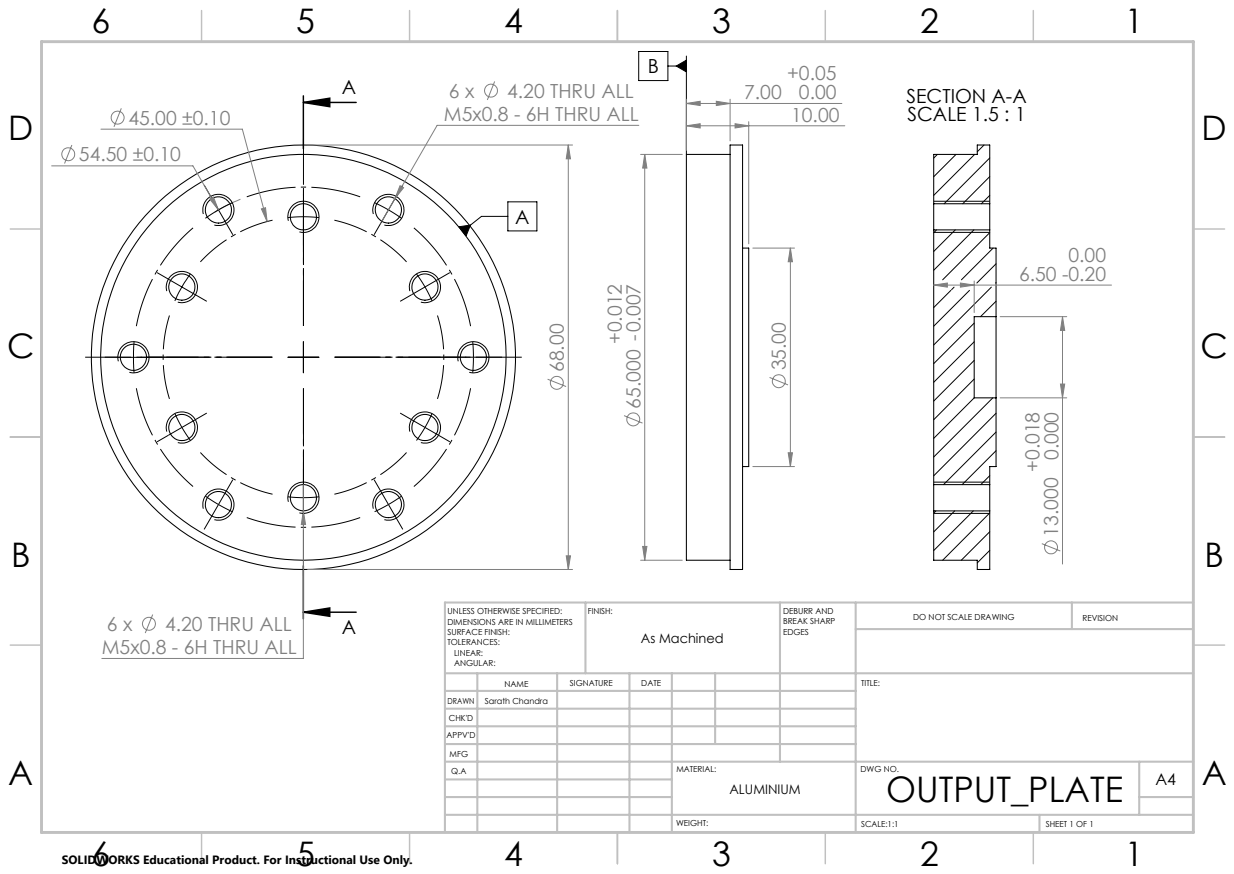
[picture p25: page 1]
4.20 THRU ALL; M5x0.8 - 6H THRU ALL; SECTION A-A SCALE 1.5 : 1; FINISH:; DEBURR AND; BREAK SHARP; DO NOT SCALE DRAWING; REVISION; SCALE:1:1; SHEET 1 OF 1; As Machined

UNLESS OTHERWISE SPECIFIED:
DIMENSIONS ARE IN MILLIMETERS
SURFACE FINISH:
TOLERANCES:
LINEAR:
ANGULAR:

NAME | SIGNATURE | DATE | | | | TITLE:

DRAWN | Sarath Chandra
CHK'D
APPV'D
MFG
Q.A | | | | MATERIAL: ALUMINIUM | DWG NO. OUTPUT_PLATE | A4

SOLIDWORKS Educational Product. For Instructional Use Only.

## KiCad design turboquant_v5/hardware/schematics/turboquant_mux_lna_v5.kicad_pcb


Board: 4 copper layers, 100.0 x 80.0 mm, 25 parts (0 on the bottom side), 3 nets.

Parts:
F1: 2A; Fuse_1206_3216Metric
J1: 12V_Input; TerminalBlock_bornier-2_P5.08mm
J2: TX_BUS; SMA_EDGE
J3: E1_GPIO; PinHeader_2x10_P2.54mm_Vertical
J4: RX0_OUT; SMA_EDGE
J5: RX1_OUT; SMA_EDGE
Q9, Q10, Q11, Q12, Q13, Q14, Q15, Q16: IRF830; TO-220-3_Vertical
U1: LM7805; TO-252-2
U2: AMS1117-3.3; SOT-223-3_TabPin2
U3, U4: DG408; SOIC-16_3.9x9.9mm_P1.27mm
U5: 74HCT595; SOIC-16_3.9x9.9mm_P1.27mm
U6, U7: OPA1641; SOIC-8_3.9x4.9mm_P1.27mm
U8, U9, U10, U11: TC4427; SOIC-8_3.9x4.9mm_P1.27mm

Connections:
+5V: U1.3, U2.3
+12V: F1.1, F1.2, J1.1, U1.1
GND: J1.2, J2.2, J4.2, J5.2, U1.2, U2.1

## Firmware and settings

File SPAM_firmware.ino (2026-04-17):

 #include <Wire.h>

#define ERROR -1
#define IDLE -1

// ===========================
// I2C DEFINITIONS
// ===========================
#define SLAVE_ADDR 0x55


// ===========================
// PIN DEFINITIONS
// ===========================
#define ARM_STEP_PIN 4
#define ARM_DIR_PIN 2

#define MUT_STEP_PIN 25
#define MUT_DIR_PIN 26


#define ARM_ENCODER_A_PIN 19 //13 = external, 19 = internal
#define ARM_ENCODER_B_PIN 18 //12 = external, 18 = internal 

#define MUT_ENCODER_A_PIN 32
#define MUT_ENCODER_B_PIN 33


#define ALERT_INTERRUPT_PIN 5
#define COLLISION_SWITCHES_PIN 15 //collision
#define ARM_HOME_PIN 34 //?
#define MUT_HOME_PIN 35



// ===========================
// ENCODER SETTINGS
// ===========================
#define ARM_ENCODER_COUNTS (4000.0) // 4000.0 for motor encoder


// ===========================
// STATUS REPORTING VARIABLES
// ===========================

#define COLLISION 0
#define ARM_POS_REACHED 1
#define MUT_POS_REACHED 2

uint8_t systemStatus = 0; // register for holding status alerts
                          // bit0 -> collision error
                          // bit1 -> arm position reached 
                          // bit2 -> mut position reached
bool armHasReportedArrival = false;
bool mutHasReportedArrival = false;




// ===========================
// ENCODER VARIABLES
// ===========================
#define GEAR_RATIO (8.55) //8.55 or 1

enum motors {
  ARM_MOTOR = 1,
  MUT_MOTOR,
  START_HOMING_SEQ
};

volatile long armEncoderPosition = 0;
volatile long mutEncoderPosition = 0;

volatile bool armLastA = 0;
volatile bool armLastB = 0;
volatile bool mutLastA = 0;
volatile bool mutLastB = 0;


long getARMEncoderPosition() {
    noInterrupts();
    long pos = armEncoderPosition;
    interrupts();
    return pos;
}

long getMUTEncoderPosition() {
    noInterrupts();
    long pos = mutEncoderPosition;
    interrupts();
    return pos;
}



// ===========================
// I2C VARIABLES
// ===========================
enum commands {
  MOVE_MOTOR_ABS = 1,
  SET_HOME,
  MOVE_MOTOR_REL,
  HALT
};

union PositionUnion {
  float value;
  uint8_t bytes[4];
};

volatile PositionUnion posUnion;

volatile int command;
volatile int motorNum;
volatile float position;


int currentMotor = -1;
int commandStatus = 0;


// ===========================
// PID PARAMETERS
// ===========================
float armKp = 1.2;
float armKi = 0.0;
float armKd = 0.05;

float armIntegral = 0;
float armLastError = 0;
//-----
float mutKp = 1.2;
float mutKi = 0.0;
float mutKd = 0.05;

float mutIntegral = 0;
float mutLastError = 0;


// ===========================
// CONTROL VARIABLES
// ===========================
long armTargetPositionCounts = 0;
long mutTargetPositionCounts = 0;

unsigned long lastControlTime = 0;
const int controlIntervalMicros = 1000; // 1 kHz loop

long armCurrentPos = 0;
long mutCurrentPos = 0;

// Stepper timing
unsigned long armLastStepTime = 0;
unsigned long mutLastStepTime = 0;

// Maximum speed in steps/sec
int maxStepRate = 800;

// ===========================
// COLLISION ISR
// ===========================
void collision_ISR(){
  reportEvent(COLLISION);
  // for(;;){} //hang if error is detected, prob not good practice to have in ISR
}


// volatile bool homing = false;
volatile bool armHoming = false;
volatile bool mutHoming = false;

// ===========================
// HOMING ISRs
// ===========================
void arm_homing_ISR(){
  if(armHoming){
    armEncoderPosition = 0;
    armTargetPositionCounts = 0;
    armHoming = false;
  }
  // else reportEvent(COLLISION);
}

void mut_homing_ISR(){
  if(mutHoming){
    mutEncoderPosition = 1000; //(long)(90 * (ARM_ENCODER_COUNTS / 360.0))
    mutTargetPositionCounts = 1000;//(long)(90 * (ARM_ENCODER_COUNTS / 360.0));
    mutHoming = false;
  }
  // else reportEvent(COLLISION);
}


// ===========================
// ENCODER ISRS
// ===========================
void IRAM_ATTR arm_ISR_encoder() {
    bool A = digitalRead(ARM_ENCODER_A_PIN);
    bool B = digitalRead(ARM_ENCODER_B_PIN);

    if (A != armLastA) {
        if (A == B) armEncoderPosition++; // CW
        else armEncoderPosition--;        // CCW
    }

    if (B != armLastB) {
        if (A != B) armEncoderPosition++; // CW
        else armEncoderPosition--;        // CCW
    }

    armLastA = A;
    armLastB = B;
}

void IRAM_ATTR mut_ISR_encoder() {
    bool A = digitalRead(MUT_ENCODER_A_PIN);
    bool B = digitalRead(MUT_ENCODER_B_PIN);

    if (A != mutLastA) {
        if (A == B) mutEncoderPosition++; // CW
        else mutEncoderPosition--;        // CCW
    }

    if (B != mutLastB) {
        if (A != B) mutEncoderPosition++; // CW
        else mutEncoderPosition--;        // CCW
    }

    mutLastA = A;
    mutLastB = B;
}


// ===========================
// I2C ISR
// ===========================
void receiveEvent(int howMany) {
  int useless = Wire.read(); //gives address but dont need it 
  command = Wire.read();
  motorNum = Wire.read();
  for (int i = 0; i < 4; i++) {
    posUnion.bytes[i] = Wire.read(); //reads float
  }

  position = posUnion.value;

  Serial.println(command);
  Serial.println(motorNum);
  Serial.println(position);
}


void requestEvent() {
    // Snapshot-then-clear so bits set between the snapshot and the
    // write-out are preserved for the next master read, instead of being
    // zeroed wholesale. Drop ALERT low only when nothing is pending.
    uint8_t snapshot = systemStatus;
    Wire.write(snapshot);
    systemStatus &= ~snapshot; // clear only the bits that were just sent
    if (systemStatus == 0) {
        digitalWrite(ALERT_INTERRUPT_PIN, LOW);
    }
}

// ===========================
// I2C FUNCTIONS
// ===========================
int commandHandler(){
  switch (command){
    case MOVE_MOTOR_ABS: 
      if(motorNum != ARM_MOTOR && motorNum != MUT_MOTOR) return ERROR;
      switch (motorNum) {
        case ARM_MOTOR:
          moveToPosition(position * GEAR_RATIO, ARM_MOTOR);
          armCurrentPos = position;
          break;
        case MUT_MOTOR:
          moveToPosition(position, MUT_MOTOR);
          mutCurrentPos = position;
          break;
      }
      

      command = IDLE; motorNum = IDLE;
      
      return MOVE_MOTOR_ABS;
    case SET_HOME:
      switch(motorNum){
        case ARM_MOTOR:
          armEncoderPosition = 0;
          armTargetPositionCounts = 0;
          break;
        case MUT_MOTOR:
          mutEncoderPosition = 0;
          mutTargetPositionCounts = 0;
          break;
      }
      
      armHoming = false;
      mutHoming = false;
      command = IDLE; motorNum = IDLE;

      return SET_HOME;
    case START_HOMING_SEQ:
      //move motors a long way so it hits the homing switches
      armHoming = true;
      mutHoming = true;
      moveToPosition(GEAR_RATIO * -360, ARM_MOTOR);
      while(armHoming){
        updatePID();
      }

      mutHoming = true;
      moveToPosition(360, MUT_MOTOR);
      while(mutHoming){
        updatePID();
      }

      // homing = false;
      command = IDLE; motorNum = IDLE;
      return START_HOMING_SEQ;
    case HALT:
      //disable motors, not implemented
      return HALT;
    default:
      return -2;
  }
}


// ===========================
// STEPPER CONTROL
// ===========================
// void stepMotor(int direction, int motorNum) {
//     switch (motorNum){
//       case ARM_MOTOR:
//         digitalWrite(ARM_DIR_PIN, direction > 0 ? HIGH : LOW);
//         digitalWrite(ARM_STEP_PIN, HIGH);
//         delayMicroseconds(2);
//         digitalWrite(ARM_STEP_PIN, LOW);
//         delayMicroseconds(2);
//         break;
//       case MUT_MOTOR:
//         digitalWrite(MUT_DIR_PIN, direction > 0 ? HIGH : LOW);
//         digitalWrite(MUT_STEP_PIN, HIGH);
//         delayMicroseconds(2);
//         digitalWrite(MUT_STEP_PIN, LOW);
//         delayMicroseconds(2);
//         break;
//     }
// }



void stepARMMotor(int direction){
  digitalWrite(ARM_DIR_PIN, direction > 0 ? HIGH : LOW);
  digitalWrite(ARM_STEP_PIN, HIGH);
  delayMicroseconds(2);
  digitalWrite(ARM_STEP_PIN, LOW);
  delayMicroseconds(2);
}

void stepMUTMotor(int direction){
  digitalWrite(MUT_DIR_PIN, direction > 0 ? LOW : HIGH);
  digitalWrite(MUT_STEP_PIN, HIGH);
  delayMicroseconds(2);
  digitalWrite(MUT_STEP_PIN, LOW);
  delayMicroseconds(2);
}


// ===========================
// PID LOOP
// ===========================
void updatePID() {
    long armCurrentPos = getARMEncoderPosition();
    long armError = armTargetPositionCounts - armCurrentPos;

    long mutCurrentPos = getMUTEncoderPosition();
    long mutError = mutTargetPositionCounts - mutCurrentPos;

    armIntegral += armError * (controlIntervalMicros / 1e6);
    float armDerivative = (armError - armLastError) / (controlIntervalMicros / 1e6);
    armLastError = armError;

    mutIntegral += mutError * (controlIntervalMicros / 1e6);
    float mutDerivative = (mutError - mutLastError) / (controlIntervalMicros / 1e6);
    mutLastError = mutError;

    float armOutput = armKp * armError + armKi * armIntegral + armKd * armDerivative;
    float mutOutput = mutKp * mutError + mutKi * mutIntegral + mutKd * mutDerivative;

    // Clamp speed
    if (armOutput > maxStepRate)  armOutput = maxStepRate;
    if (armOutput < -maxStepRate) armOutput = -maxStepRate;

    if (mutOutput > maxStepRate)  mutOutput = maxStepRate;
    if (mutOutput < -maxStepRate) mutOutput = -maxStepRate;

    // Convert to step interval
    if (armOutput != 0) {
        unsigned long stepInterval = 1000000.0 / abs(armOutput); // microseconds per step
        unsigned long now = micros();
        if (now - armLastStepTime >= stepInterval) {
            armLastStepTime = now;
            int direction = (armOutput > 0) ? 1 : -1;
            stepARMMotor(direction);
        }
    }

    if (mutOutput != 0) {
        unsigned long stepInterval = 1000000.0 / abs(mutOutput); // microseconds per step
        unsigned long now = micros();
        if (now - mutLastStepTime >= stepInterval) {
            mutLastStepTime = now;
            int direction = (mutOutput > 0) ? 1 : -1;
            stepMUTMotor(-direction);
        }
    }

    // Debug print
    static unsigned long lastDebug = 0;
    if (millis() - lastDebug >= 50) { // 20 Hz
        lastDebug = millis();
        Serial.print("ARM Target=");
        Serial.print(armTargetPositionCounts);
        Serial.print(" ARM Pos=");
        Serial.print(armCurrentPos);
        Serial.print(" ARM Err=");
        Serial.println(armError);
        Serial.print("armHasReportedArrival: ");
        Serial.println(armHasReportedArrival);

        Serial.print("MUT Target=");
        Serial.print(mutTargetPositionCounts);
        Serial.print(" MUT Pos=");
        Serial.print(mutCurrentPos);
        Serial.print(" MUT Err=");
        Serial.println(mutError);
        Serial.print("mutHasReportedArrival: ");
        Serial.println(mutHasReportedArrival);
        Serial.print("armHoming: ");
        Serial.println(armHoming);
        Serial.print("mutHoming: ");
        Serial.println(mutHoming);
        Serial.println("------------------------------------");
    }
}


// ===========================
// MOVE FUNCTION
// ===========================
void moveToPosition(float degrees, int motorNum) {
    switch (motorNum){
      case ARM_MOTOR:
        if(!armHoming && degrees > 80) degrees = 80; // clamp local degrees, not the global position
        armTargetPositionCounts = (long)(degrees * (ARM_ENCODER_COUNTS / 360.0)); // encoder counts per degree
        armHasReportedArrival = false; // only reset the flag for the motor being moved
        break;
      case MUT_MOTOR:
        mutTargetPositionCounts = (long)(degrees * (4000.0 / 360.0)); // encoder counts per degree
        mutHasReportedArrival = false; // only reset the flag for the motor being moved
        break;
    }
    Serial.print("motorNum: ");
    Serial.print(motorNum);
    Serial.print("MoveTo: ");
    Serial.print(degrees);
    Serial.print("arm deg -> ");
    Serial.print(armTargetPositionCounts);
    Serial.println(" counts");
    Serial.print("mut deg -> ");
    Serial.print(mutTargetPositionCounts);
    Serial.println(" counts");
}


// ===========================
// CHECK IF POSITION REACHED
// ===========================
bool positionReached(long toleranceCounts = 5, int motorNum = 0) { // ~1 deg, x/4000 = 1/360 -> x = 11.11, ~0.5 deg -> x = 5.55
    long pos;
    if(motorNum == ARM_MOTOR) pos = getARMEncoderPosition();
    if(motorNum == MUT_MOTOR) pos = getMUTEncoderPosition();
    
    // long pos = getEncoderPosition(motorNum);
    long err;
    switch (motorNum) {
      case ARM_MOTOR:
        err = abs(armTargetPositionCounts - pos);
        break;
      case MUT_MOTOR:
        err = abs(mutTargetPositionCounts - pos);
        break;
    }
    return (err <= toleranceCounts);
}

void reportEvent(uint8_t bitIndex) {
    systemStatus |= (1 << bitIndex); // Set the specific bit
    digitalWrite(ALERT_INTERRUPT_PIN, HIGH); // Alert the Pi
}


// ===========================
// SETUP
// ===========================
void setup() {
    Wire.begin(SLAVE_ADDR);
    Wire.onReceive(receiveEvent);
    Wire.onRequest(requestEvent);

    Serial.begin(115200);
    while(!Serial); //halt until serial is set up

    pinMode(ARM_STEP_PIN, OUTPUT);
    pinMode(ARM_DIR_PIN, OUTPUT);
    pinMode(ARM_ENCODER_A_PIN, INPUT_PULLUP);
    pinMode(ARM_ENCODER_B_PIN, INPUT_PULLUP);

    pinMode(MUT_STEP_PIN, OUTPUT);
    pinMode(MUT_DIR_PIN, OUTPUT);
    pinMode(MUT_ENCODER_A_PIN, INPUT_PULLUP);
    pinMode(MUT_ENCODER_B_PIN, INPUT_PULLUP);

    pinMode(ALERT_INTERRUPT_PIN, OUTPUT);

    pinMode(COLLISION_SWITCHES_PIN, INPUT_PULLUP); //INPUT??

    pinMode(ARM_HOME_PIN, INPUT); //INPUT??
    pinMode(MUT_HOME_PIN, INPUT); //INPUT??



    digitalWrite(ALERT_INTERRUPT_PIN, LOW);

    attachInterrupt(digitalPinToInterrupt(ARM_ENCODER_A_PIN), arm_ISR_encoder, CHANGE);
    attachInterrupt(digitalPinToInterrupt(ARM_ENCODER_B_PIN), arm_ISR_encoder, CHANGE);

    attachInterrupt(digitalPinToInterrupt(MUT_ENCODER_A_PIN), mut_ISR_encoder, CHANGE);
    attachInterrupt(digitalPinToInterrupt(MUT_ENCODER_B_PIN), mut_ISR_encoder, CHANGE);

    attachInterrupt(digitalPinToInterrupt(ARM_HOME_PIN), arm_homing_ISR, HIGH);
    attachInterrupt(digitalPinToInterrupt(MUT_HOME_PIN), mut_homing_ISR, HIGH); 


    armLastA = digitalRead(ARM_ENCODER_A_PIN);
    armLastB = digitalRead(ARM_ENCODER_B_PIN);

    mutLastA = digitalRead(MUT_ENCODER_A_PIN);
    mutLastB = digitalRead(MUT_ENCODER_B_PIN);

    Serial.println("Stepper PID Controller Ready");
}


// ===========================
// MAIN LOOP
// ===========================
void loop() {
    // PID update + position-reached check at 1 kHz.
    // Running the position-reached check inside this gate stops it from
    // firing tens of thousands of times per second on every loop() pass.
    unsigned long now = micros();
    if (now - lastControlTime >= controlIntervalMicros) {
        lastControlTime = now;
        updatePID();

        if (!armHasReportedArrival && positionReached(20, ARM_MOTOR)) {
            Serial.println("ARM POSITION REACHED");
            reportEvent(ARM_POS_REACHED);
            armHasReportedArrival = true;
        }
        if (!mutHasReportedArrival && positionReached(20, MUT_MOTOR)) {
            Serial.println("MUT POSITION REACHED");
            reportEvent(MUT_POS_REACHED);
            mutHasReportedArrival = true;
        }
    }


// COMMAND STATE MACHINE
  if(command != IDLE) {
    commandStatus = commandHandler();
    if (commandStatus == ERROR){ //add more error statements
      Serial.println("COMMAND HANDLER ERROR");
      for(;;);
    }
    if(systemStatus == 1 << COLLISION){
      Serial.println("COLLISION DETECTED. HALTING");
      for(;;); //implement enable pin to truly stop motors?
    }
  }


}

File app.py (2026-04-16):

"""
SPAMGui assembly — combines all mixins into the final application class.
"""

import tkinter as tk
import os
import platform
import threading

from gui.themes import THEMES
from gui.widgets import WidgetsMixin
from gui.config import ConfigMixin
from gui.hardware_mixin import HardwareMixin
from gui.db_helpers import DBMixin
from gui.measurement import MeasurementMixin
from gui.extraction import ExtractionMixin
from gui.graphs import GraphsMixin
from gui.callbacks import CallbacksMixin
from gui.panels.menu import MenuMixin
from gui.panels.status_bar import StatusBarMixin
from gui.panels.sidebar import SidebarMixin
from gui.panels.detail_panel import DetailPanelMixin
from gui.dialogs.base import DialogBaseMixin
from gui.dialogs.extraction_dlg import ExtractionDialogMixin
from gui.dialogs.parameters_dlg import ParametersDialogMixin
from gui.dialogs.connection_dlg import ConnectionDialogMixin

if platform.system() == 'Windows':
    try:
        from ctypes import windll
        windll.shcore.SetProcessDpiAwareness(1)
    except:
        pass


class SPAMGui(
    WidgetsMixin,
    ConfigMixin,
    HardwareMixin,
    DBMixin,
    MeasurementMixin,
    ExtractionMixin,
    GraphsMixin,
    CallbacksMixin,
    MenuMixin,
    StatusBarMixin,
    SidebarMixin,
    DetailPanelMixin,
    DialogBaseMixin,
    ExtractionDialogMixin,
    ParametersDialogMixin,
    ConnectionDialogMixin,
    tk.Tk,
):
    """Main application window for the SPAM GUI."""

    def __init__(self) -> None:
        super().__init__()
        self.title("SPAM - Scanner for Polarized Anisotropic Materials")

        self.config_file = os.path.join(os.path.dirname(__file__), 'spam_config.json')
        self.connection_settings = self._load_connection_settings()

        saved_theme = self.connection_settings.get('theme', 'dark')
        self.theme = THEMES.get(saved_theme, THEMES["dark"])
        self._theme_name = saved_theme

        screen_w = self.winfo_screenwidth()
        screen_h = self.winfo_screenheight()
        if platform.system() == 'Windows':
            self.state('zoomed')
        else:
            self.geometry(f"{min(screen_w, 1920)}x{min(screen_h, 1080)}")
            self.update_idletasks()
            x = (screen_w - self.winfo_width()) // 2
            y = (screen_h - self.winfo_height()) // 2
            self.geometry(f"+{x}+{y}")

        self.configure(bg=self.theme['bg'])
        self.is_fullscreen = False
        self.resize_timer = None
        self.resize_delay = 150

        self.debug_log = []
        self.debug_window = None

        self.is_measuring = False
        self.measurement_thread = None
        self.current_angle = 0.0
        self.current_permittivity = 0.00
        self.current_permeability = 0.00

        self.transmitted_power = 0.0
        self.reflected_power = 0.0
        self.transmitted_phase = 0.0
        self.reflected_phase = 0.0

        self.s11_mag = 0.0; self.s11_phase = 0.0
        self.s12_mag = 0.0; self.s12_phase = 0.0
        self.s21_mag = 0.0; self.s21_phase = 0.0
        self.s22_mag = 0.0; self.s22_phase = 0.0

        self.angle_step = 5.0
        self.measurement_interval = 0.5
        self.adc_samples_per_point = int(self.connection_settings.get('adc_samples_per_point', '8'))

        self.calibration_error = 0.0
        self.noise_level = 0.0

        # Calibration state (Through + Reflect reference voltages)
        self.cal_through = None   # {angle: complex} or None
        self.cal_reflect = None   # {angle: complex} or None
        self.cal_d = self._safe_float(
            self.connection_settings.get('cal_d_m', '0.0'), 0.0
        )
        self.cal_d_sheet = self._safe_float(
            self.connection_settings.get('cal_d_sheet_m', '0.0'), 0.0
        )
        self._cal_running = False
        self._cal_missing_warned = False

        self.motor_control_enabled = False
        self.motor_bus = None
        self.motor_gpio = None
        self.motor_movement_status = True
        self.motor_collision_detected = False
        self.motor_num = 1
        self.motor_command = 1
        self._motor_done_seq = 0    # incremented by ISR on each move-complete edge
        self._motor_expect_seq = 0  # set by _send_motor_command before each write
        self._i2c_lock = threading.Lock()  # serialise all motor_bus access
        self.motor_status_var = tk.StringVar(value="Not Initialized")
        self.motor_position_var = tk.StringVar(value="0.0\u00b0")

        self.servo = None
        self.servo_angle = 0.0
        self.current_polarization = 0.0

        self.adc = None
        self.rf_switch = None
        self.rf_switch_enabled = str(self.connection_settings.get('enable_rf_switch', '0')).strip().lower() in ('1', 'true', 'yes', 'on')
        self._adc_only_hint_logged = False

        self._last_graph_count = -1
        self.adc_demo_window_sec = 20.0
        self.adc_demo_graph_enabled = True
        self._sweep_pts_pol0 = 0
        self._sweep_pts_pol90 = 0
        self.adc_demo_t = []
        self.adc_demo_tx_v = []
        self.adc_demo_rx_v = []
        self.adc_demo_sample_count = 0
        self.adc_demo_sample_rate_hz = 0.0
        self.adc_demo_t0 = None
        self._adc_stream_running = False
        self._adc_stream_thread = None
        self._adc_lock = threading.Lock()

        self.extraction_f0_ghz = self._safe_float(
            self.connection_settings.get('extraction_f0_ghz', '24.0'), 24.0
        )
        self.extraction_d_mil = self._safe_float(
            self.connection_settings.get('extraction_d_mil', '60.0'), 60.0
        )
        self.extraction_tensor_type = self.connection_settings.get('extraction_tensor_type', "diagonal")
        if self.extraction_tensor_type not in ("isotropic", "diagonal", "symmetric"):
            self.extraction_tensor_type = "diagonal"
        self.extraction_thread = None
        self.extraction_running = False
        self.extraction_status_var = tk.StringVar(value="Not Run")
        self.extraction_error_var = tk.StringVar(value="--")
        self.extraction_eps_var = tk.StringVar(value="--")
        self.extraction_mu_var = tk.StringVar(value="--")

        self.after(200, self._initialize_hardware)

        self._configure_ttk_style()
        self._create_menu()
        self._create_status_bar()
        self._create_sidebar()
        self._create_detail_panel()
        self._create_center_panel()

        if hasattr(self, 'start_container') and hasattr(self, 'stop_container'):
            self._update_button_states()

        self.after(100, self._initialize_background)
        self.protocol("WM_DELETE_WINDOW", self._on_close)
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

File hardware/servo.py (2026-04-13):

"""
Hiwonder HPS-2518MG PWM Servo Driver

Standard hobby servo: 50 Hz, 1000-2000 µs pulse width -> 0-180 degrees.
Uses pigpio (DMA hardware PWM, jitter-free) when available, falls back to
RPi.GPIO software PWM. On non-Linux platforms, operates in simulation mode.

Wiring:
  Red    -> 5V-6V power supply (dedicated, NOT Pi 3.3V rail)
  Black  -> GND (shared with Pi)
  Orange -> GPIO signal pin (BCM 18 default)

pigpio setup (recommended, eliminates jitter):
  sudo apt install pigpio python3-pigpio -y
  sudo systemctl enable pigpiod
  sudo systemctl start pigpiod
"""

import platform
import time

_PULSE_MIN_US = 850     # pulse width at 0 degrees — horizontal polarization (calibrated)
_PULSE_MAX_US = 1800    # pulse width at 90 degrees — vertical polarization (calibrated)
_PWM_FREQ_HZ  = 50
_PERIOD_US    = 20000   # 1 / 50 Hz = 20 ms

_SIM_MODE   = False
_USE_PIGPIO = False
_pigpio     = None
_GPIO       = None

try:
    import pigpio as _pigpio
    _USE_PIGPIO = True
except ImportError:
    try:
        import RPi.GPIO as _GPIO
    except ImportError:
        _SIM_MODE = True


class HPS2518Servo:
    """PWM-controlled Hiwonder HPS-2518MG hobby servo (0-180 degrees).

    Prefers pigpio for hardware-accurate, jitter-free DMA PWM.
    Falls back to RPi.GPIO software PWM if pigpio is unavailable or its
    daemon is not running.

    Parameters
    ----------
    gpio_pin : int
        BCM GPIO pin number connected to the servo signal wire.
    log_fn : callable, optional
        Logging callback ``log_fn(message, level)``.
    """

    def __init__(self, gpio_pin: int = 18, log_fn=None):
        self._log = log_fn or (lambda m, l: None)
        self._pin = gpio_pin
        self._sim = _SIM_MODE or platform.system() != 'Linux'
        self._angle = None
        self._pi  = None   # pigpio connection
        self._pwm = None   # RPi.GPIO PWM object

        if self._sim:
            self._log(
                f"HPS2518Servo: simulation mode (GPIO not available), pin={gpio_pin}",
                "WARNING"
            )
            return

        if _USE_PIGPIO:
            self._pi = _pigpio.pi()
            if self._pi.connected:
                self._pi.set_servo_pulsewidth(self._pin, 0)
                self._angle = None
                self._log(
                    f"HPS2518Servo: initialized (pigpio) on GPIO{gpio_pin}, PWM idle",
                    "SUCCESS"
                )
            else:
                self._log("pigpio daemon not running — falling back to RPi.GPIO", "WARNING")
                self._pi = None
                self._init_rpigpio(gpio_pin)
        else:
            self._init_rpigpio(gpio_pin)

    def _init_rpigpio(self, gpio_pin: int):
        _GPIO.setwarnings(False)
        _GPIO.setmode(_GPIO.BCM)
        _GPIO.setup(self._pin, _GPIO.OUT)
        self._pwm = _GPIO.PWM(self._pin, _PWM_FREQ_HZ)
        self._pwm.start(0)
        self._angle = None
        self._log(
            f"HPS2518Servo: initialized (RPi.GPIO) on GPIO{gpio_pin}, PWM idle",
            "SUCCESS"
        )

    def move_to(self, angle: float, settle_s: float = 0.5):
        """Command servo to *angle* degrees (0-180). Blocks for *settle_s* seconds.

        Parameters
        ----------
        angle : float
            Target angle in degrees, clamped to [0, 180].
        settle_s : float
            Seconds to wait after commanding the servo to let it reach position.
        """
        angle = max(0.0, min(90.0, angle))

        if self._sim:
            self._log(f"HPS2518Servo: (sim) -> {angle:.1f}°", "INFO")
            self._angle = angle
            return

        pulse_us = int(_PULSE_MIN_US + (angle / 90.0) * (_PULSE_MAX_US - _PULSE_MIN_US))

        if self._pi is not None:
            self._pi.set_servo_pulsewidth(self._pin, pulse_us)
            time.sleep(settle_s)
            self._pi.set_servo_pulsewidth(self._pin, 0)
            self._angle = angle
            self._log(f"HPS2518Servo: -> {angle:.1f}° (pulse={pulse_us}µs, released)", "INFO")
        elif self._pwm is not None:
            duty = self._angle_to_duty(angle)
            self._pwm.ChangeDutyCycle(duty)
            time.sleep(settle_s)
            self._pwm.ChangeDutyCycle(0)
            self._angle = angle
            self._log(f"HPS2518Servo: -> {angle:.1f}° (duty={duty:.2f}%, released)", "INFO")

    @property
    def current_angle(self) -> float | None:
        """Current commanded angle in degrees, or None if not yet set."""
        return self._angle

    @property
    def is_simulated(self) -> bool:
        """True when running in simulation mode (no real GPIO)."""
        return self._sim

    @property
    def backend(self) -> str:
        """Active PWM backend: 'pigpio', 'RPi.GPIO', or 'sim'."""
        if self._sim:
            return 'sim'
        return 'pigpio' if self._pi is not None else 'RPi.GPIO'

    def close(self):
        """Stop PWM output and release the GPIO pin."""
        if self._pi is not None:
            try:
                self._pi.set_servo_pulsewidth(self._pin, 0)
                self._pi.stop()
            except Exception:
                pass
            self._pi = None
        if self._pwm is not None:
            try:
                self._pwm.stop()
            except Exception:
                pass
            self._pwm = None
        if not self._sim and _GPIO is not None:
            try:
                _GPIO.cleanup(self._pin)
            except Exception:
                pass
        self._angle = None

    @staticmethod
    def _angle_to_duty(angle: float) -> float:
        """Convert 0-90 degrees to duty cycle percent for 50 Hz PWM."""
        pulse_us = _PULSE_MIN_US + (angle / 90.0) * (_PULSE_MAX_US - _PULSE_MIN_US)
        return (pulse_us / _PERIOD_US) * 100.0

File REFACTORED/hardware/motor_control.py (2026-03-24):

"""
Motor control via I2C and GPIO for Raspberry Pi.
Handles motor initialization, command sending, position waiting, and GPIO interrupts.
"""
import platform
import time


class MotorController:
    """Manages motor control hardware (I2C bus + GPIO interrupts)."""

    def __init__(self, settings: dict, log=None, gui_after=None):
        """
        Args:
            settings:  connection_settings dict (i2c_bus, microcontroller_address, isr_pin …)
            log:       callable(message, level) for debug logging
            gui_after: callable(ms, fn) for scheduling GUI-safe callbacks
        """
        self.settings = settings
        self._log = log or (lambda msg, lvl="INFO": print(f"[{lvl}] {msg}"))
        self._after = gui_after  # may be None outside GUI context

        self.enabled = False
        self.bus = None
        self.gpio = None
        self.movement_ready = True     # True = idle/ready, False = moving
        self.collision_detected = False

        # Public callbacks – the GUI sets these after construction
        self.on_collision = None       # callable()
        self.on_position_reached = None  # callable()

    # ------------------------------------------------------------------
    # Initialization
    # ------------------------------------------------------------------
    def initialize(self):
        """Initialize I2C bus and GPIO interrupt on Raspberry Pi."""
        if platform.system() != 'Linux':
            self._log("Motor control not available on this platform – simulation mode", "INFO")
            return

        try:
            from smbus import SMBus
            import RPi.GPIO as GPIO

            i2c_bus_num = int(self.settings.get('i2c_bus', '1'))
            mcu_address = int(self.settings.get('microcontroller_address', '0x55'), 16)
            isr_pin = int(self.settings.get('isr_pin', '17'))

            self._log(f"Initializing motor control: I2C Bus={i2c_bus_num}, "
                      f"Address=0x{mcu_address:02X}, ISR Pin={isr_pin}", "INFO")

            # I2C
            self.bus = SMBus(i2c_bus_num)
            self._log(f"I2C bus {i2c_bus_num} opened successfully", "INFO")

            # Probe
            try:
                status = self.bus.read_byte_data(mcu_address, 0x00)
                self._log(f"Microcontroller detected at 0x{mcu_address:02X}, "
                          f"status=0x{status:02X}", "SUCCESS")
            except Exception as e:
                self._log(f"Could not read from microcontroller at 0x{mcu_address:02X}: {e}", "WARNING")

            # GPIO
            GPIO.setmode(GPIO.BCM)
            GPIO.setup(isr_pin, GPIO.IN)
            self.gpio = GPIO
            self._log(f"GPIO pin {isr_pin} configured for interrupt detection", "INFO")

            # Interrupt handler
            def _handle_alert(channel):
                try:
                    status = self.bus.read_byte_data(mcu_address, 0x00)
                    if status & 0x01:
                        self.collision_detected = True
                        if self.on_collision:
                            self.on_collision()
                    if status & 0x02:
                        self.movement_ready = True
                        if self.on_position_reached:
                            self.on_position_reached()
                except Exception as e:
                    self._log(f"Error reading motor status: {e}", "ERROR")

            GPIO.add_event_detect(isr_pin, GPIO.RISING, callback=_handle_alert)
            self._log(f"GPIO interrupt handler registered on pin {isr_pin}", "INFO")
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

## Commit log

2026-02-03 Enhanced GUI with S-parameters display, control panel, settings dialogs, and startup optimizations
    - Added S-parameter display (S11, S12, S21, S22) in info panel
    - Created control panel with measurement parameters and non-idealities section
    - Removed S-parameter conversion formulas section
    - Made right panel more compact and uniform
    - Implemented Adjust Parameters dialog for measurement settings
    - Implemented Connection Setup dialog for VNA and serial connections
    - Updated calibration process to two-step (empty then material)
    - Optimized startup scripts to skip dependency install if already present
    - Deferred database initialization for faster UI startup
    - Added resize debouncing to prevent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
2026-02-03 Update README with comprehensive installation and usage instructions
    - Added detailed installation steps for Windows and Linux/Raspberry Pi
    - Included both quick start and manual installation options
    - Expanded usage guide with step-by-step instructions
    - Added calibration process documentation (two-step process)
    - Documented all GUI features and interface sections
    - Enhanced hardware integration section with VNA and serial examples
    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
2026-02-03 Restore GUI features and update to I2C/ADC architecture - Resolved merge conflicts in GUI.py restoring all features (settings dialogs, S-parameters, control panel) - Updated connection settings from 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
    [GUI.py]
2026-02-10 Add motor control integration and database modules
    - Integrated motor control from motor_control_status.py into GUI
    - Added automatic motor movement during measurements (0-90 degrees)
    - Added manual motor control tab in Debug Console
    - Removed mock data generation from measurement worker
    - Created backend/database.py and backend/models.py for database functionality
    - Added motor status display in info panel
    - Improved motor initialization with connection verification
    - Added collision detection and position feedback via GPIO interrupts
    [GUI.py]
2026-02-12 Fix motor control command format and add settings persistence
    - Fixed motor command format to use 6-byte float encoding [command, motor, float_bytes...]
    - Changed default motor to 1 (arm) and command byte to 1
    - Added detailed command logging in Debug Console
    - Added connection settings persistence to spam_config.json
    - Fixed connection setup dialog to properly save and reload settings
    - Improved startup script to handle DNS issues and system packages
    - Added backend database modules (database.py, models.py)
    - Enhanced motor control initialization with better error handling
    [GUI.py]
2026-03-24 Enhance SPAM application with new features and database migration
    - Introduced theme palettes for dark and light modes in the GUI.
    - Added new model `ExtractionResult` for T-matrix material extraction results.
    - Updated `Measurement` model to include additional fields for power and phase.
    - Implemented database migration function to add missing columns for backward compatibility.
    - Updated `requirements.txt` to include `scipy` for material extraction computations.
    - Expanded README with integration testing details for motor control and calibration processes.
    [GUI.py, debug_console.py]
2026-03-26 Remove obsolete documentation files and refactor GUI hardware initialization
    - Deleted outdated documentation files: ARDUINO_PYTHON_CONNECTION.md, CODE_STRUCTURE.tex, GUI_DOCUMENTATION.tex, PROGRESS_UPDATE.md, and REFACTORING_ANALYSIS.md.
    - Refactored GUI.py to consolidate hardware initialization into a single method, `_initialize_hardware`, improving clarity and maintainability.
    - Updated connection settings in spam_config.json to include new parameters for SPI and ADC configurations.
    - Enhanced error handling in the motor control logic to ensure robust operation across platforms.
    [GUI.py, ad7193.py, debug_console.py]
2026-03-31 ADC update
2026-04-02 demo adc
2026-04-02 ADC Script
2026-04-02 MAX ADC
2026-04-02 ADC f9x
2026-04-02 cpp adc
2026-04-02 ADC Changes
2026-04-06 increase adc gui
2026-04-06 samples patch
2026-04-06 ADC path
2026-04-06 ADC fix??
2026-04-06 ADC Graph Update
2026-04-12 Servo and math
2026-04-12 servo: switch to pigpio DMA PWM to eliminate jitter, RPi.GPIO fallback
    [servo.py]
2026-04-12 servo: calibrate pulse range to 900-2200us for this unit
2026-04-13 expo polish: dual-pol S-matrix, live S-param display, graph overhaul, sweep progress, ADC always-on
2026-04-13 perf: dpi=72, no tight_layout in loop, capped graph query, 20Hz ADC stream, 20s buffer
    [app.py, db_helpers.py, graphs.py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]
2026-04-13 add servo_test.py calibration script
2026-04-13 servo: calibrate 850us=0deg(H) 1800us=90deg(V), fix angle math to 0-90 range
    [servo.py]
2026-04-13 fix servo jitter: no PWM on init, release signal after each move
    [servo.py]
2026-04-13 fix: servo second sweep sends 90deg not 180deg
    [measurement.py]
2026-04-13 expo fixes: export all fields+extraction, cal guard, motor reset, servo GPIO UI, cal status row, dot reset, log to file, v2.0
    [callbacks.py, config.py, connection_dlg.py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]
2026-04-13 docs: update REPO_CONTEXT for servo calibration + expo fixes (2026-04-13)
2026-04-13 docs: update README for v2.0 expo build (dual-pol, servo, RF switch, VNC, current status)
2026-04-14 startup homing
2026-04-14 ADC Plot Polish
2026-04-14 ADC plot
2026-04-14 homing fix
2026-04-14 adc and distance measurements
2026-04-14 adc fix
2026-04-14 adc test script
2026-04-14 ADC and stop fix
    [ad7193.py, graphs.py, measurement.py]
2026-04-14 adc single stream
2026-04-14 choppiness fix and adc patch
    [ad7193.py, measurement.py]
2026-04-14 adc bug fix please!!
    [ad7193.py, measurement.py]
2026-04-14 ADC Sampling
2026-04-14 spi lock
2026-04-15 Idle mode verification fix and angle update guard
    [ad7193.py, graphs.py]
2026-04-15 ADC warmup and dual-channel read fix
    [ad7193.py, measurement.py]
2026-04-15 ADC warmup convergence detection and adaptive settling
2026-04-15 Timeout recovery reset and fixed-count warmup flush
    [ad7193.py]
2026-04-15 Continuous ADC read test with CLI args and live stats
2026-04-15 better adc test script
2026-04-15 adc test graph
2026-04-16 ADC-only averaging — replace fragile read_iq_stream() unpacking with explicit read_channel(0) / read_channel(1) calls in _avg_stream_reads for ADC-only mode Clear measurements on Start — auto-delete 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
    [callbacks.py, measurement.py]
2026-04-16 I2C bus recovery and ADC timeout hardening — add _recover_i2c_bus() to reopen SMBus on EIO/EREMOTEIO, 50ms settle after motor commands to prevent SPI glitch, abort sweep after 3 consecutive motor fai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
    [ad7193.py, hardware_mixin.py, measurement.py]
2026-04-16 Motor I2C lock and sequence-based ISR synchronization — add _i2c_lock to serialize all motor_bus access, replace motor_movement_status boolean with _motor_done_seq/_motor_expect_seq counters to elimi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
    [app.py, hardware_mixin.py, measurement.py]
2026-04-16 Remove ISR-based motor wait path and always poll I2C status register — delete ISR sequence check fallback since MCU only pulses GPIO17 for homing (not regular moves), always poll 0x02 bit in two phas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
2026-04-16 Increase material motor timeout from 10s to 20s to prevent premature timeout on slower rotations
    [measurement.py]
2026-04-16 Add material motor tracking during Through and Short calibrations — introduce _cal_material_angle() helper to compute material position (45° + arm_angle/5 * 2.5), move material motor before each volt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
    [callbacks.py]
2026-04-16 Move material motor before arm motor in measurement sweep to prevent lag — reorder motor commands in _sweep_one_polarization() to position material first (matching calibration order), add instant-com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
    [callbacks.py, extraction.py, graphs.py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]
2026-04-16 requestEvent — clears only bits that were sent, not the whole register moveToPosition — resets only the arrival flag for the motor being commanded (fixes the spurious ARM_POS_REACHED that caused prem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
    positionReached check moved inside 1 kHz block
    lastControlTime reset after both blocking homing loops
    MUT_ENCODER_COUNTS and MUT_HOME_OFFSET_COUNTS constants added
    All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
    [SPAM_firmware.ino]
2026-04-16 adc leep
2026-04-16 changes to adc
2026-04-16 RF Switch time increase
2026-04-17 Cal motor fail tolerance (3 strikes) + disable collision detect
    [callbacks.py, hardware_mixin.py]
2026-04-17 Revert "Cal motor fail tolerance (3 strikes) + disable collision detect"
    [callbacks.py, hardware_mixin.py]
2026-04-17 Fix motor movement race condition between ISR and polling
    Add checks for `_motor_done_seq >= _motor_expect_seq` in both wait phases to handle race condition where ISR's `handle_alert` and polling both read systemStatus. Since firmware's requestEvent clears status on every I2C read, whichever side reads first consumes the ARM_POS_REACHED bit. Now either path can detect completion to prevent starvation.
    [hardware_mixin.py]
2026-04-17 back to fixed sweep
    [measurement.py]
2026-04-24 Mech and PCB
    [17HS4401S Stepper Motor.step, 200_mm_steel_rod.SLDPRT, 3709N19_At Series Timing Belt Pulley.SLDPRT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]
2026-04-28 power doc + budgets
2026-04-30 irrelevant pcbs
    [Board 2.PrjPcb, Board 3.PrjPcb, Board 3.xlsx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]
